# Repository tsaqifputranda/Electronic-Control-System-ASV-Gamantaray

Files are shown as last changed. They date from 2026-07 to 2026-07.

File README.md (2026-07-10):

# 🔧 Electronic (Control System) - ASV Gamantaray

Selamat datang di dokumentasi sistem kontrol elektronika kapal otonom Gamantaray.

## 📋 Daftar Isi Dokumentasi
1. **Project Overview** (Halaman Utama)
2. [Spesifikasi Sistem (Requirements)](./02_Requirements/requirements.md)
3. [Arsitektur & Diagram Blok](./03_System_Architecture/architecture.md)
4. [Desain Hardware & PCB](./04_Hardware_Design/hardware_desain.md)
5. [Power Management](./05_Power_Management/power_management.md)
6. [Wiring & Integration](./06_Wiring_&_Integration/integration_notes.md)
7. [Testing](./07_Testing/test_procedures.md)
8. [Problem & Solution](./08_Problem_&_Solution/troubleshooting.md)
9. [Final Evaluation](./09_Final_Evaluation/final_evaluation.md)
10. [Next Generation Notes](./10_Next_Generation_Notes/next_generation_notes.md)

---

## 🔌 Diagram Blok Sistem Utama
Untuk gambaran cepat mengenai interkoneksi sistem, kamu bisa melihat ringkasan diagram melalui tautan di bawah ini:

* ⚡ [Buka Diagram Blok Distribusi Daya Sistem Kontrol](./03_System_Architecture/PDB_Control_System_Diagram.jpg)
* 🗺️ [Buka Diagram Arsitektur Komunikasi Antar Komponen](./03_System_Architecture/Communication_Architecture_Diagram.jpg)

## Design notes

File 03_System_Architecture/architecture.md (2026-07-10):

# 🏗️ Arsitektur Sistem, Komunikasi & Pengabelan ASV Gamantaray 

Dokumen ini menjelaskan arsitektur tingkat tinggi (high-level architecture), topologi jaringan komunikasi, serta detail pengabelan sinyal kontrol pada kapal otonom ASV Gamantaray Safinah One 2026.

---

## 1. Arsitektur Jaringan & Distribusi Komponen (System Architecture)

Diagram di bawah ini menunjukkan distribusi fisik komponen antara lambung kapal (Hull A & Hull B), susunan geladak (Deck A & Deck B), serta jalur komunikasi ke Stasiun Pengendali Darat (Ground Control Station - GCS).

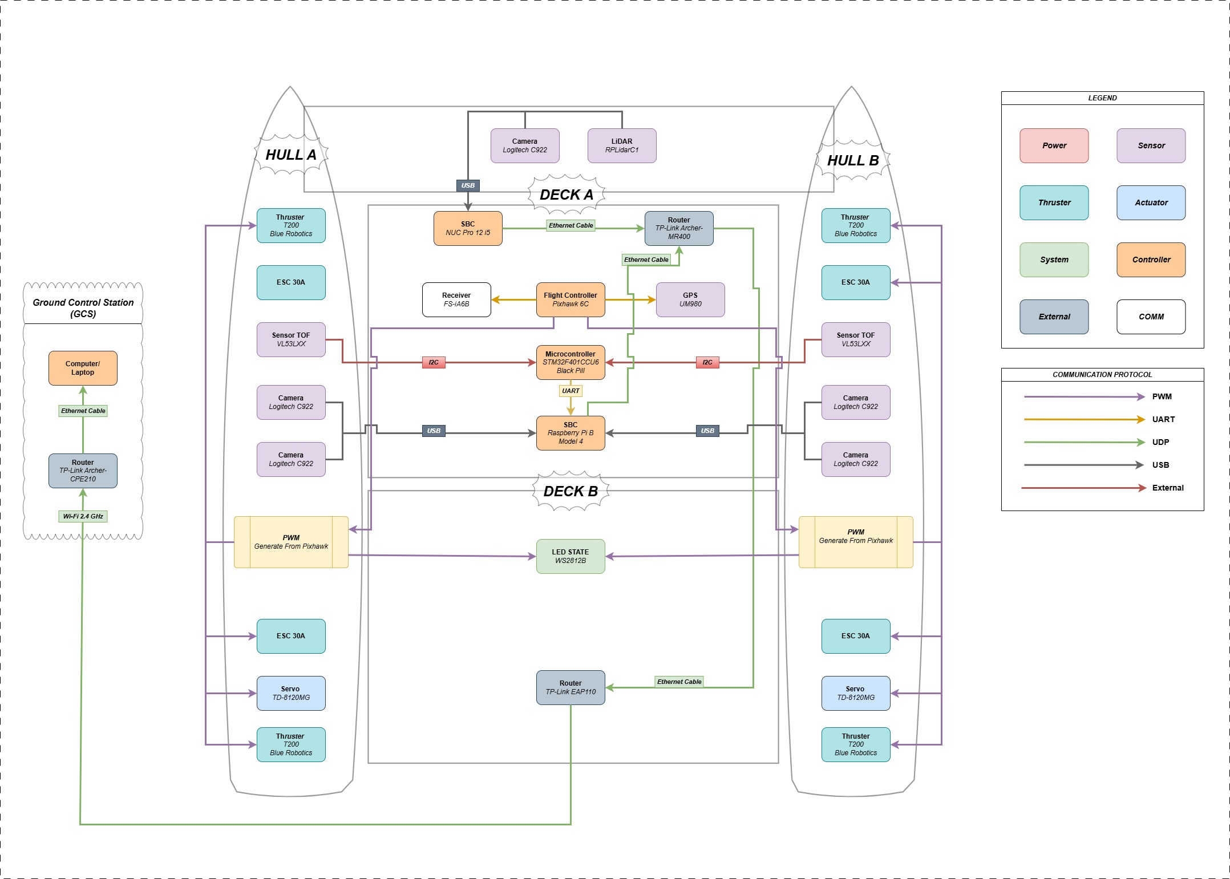
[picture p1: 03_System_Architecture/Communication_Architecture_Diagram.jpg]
Arsitektur Komunikasi Sistem


### A. Pembagian Kompartemen Fisik
* **HULL A & HULL B (Sistem Penggerak & Sensor Samping):** Masing-masing lambung dilengkapi dengan 2x Thruster Blue Robotics T200 (dikendalikan via ESC 30A), 1x Servo TD-8120MG untuk artikulasi mekanik, 1x Sensor Jarak TOF VL53LXX, dan 2x Kamera Logitech C922.
* **DECK A (Pusat Komputasi & Navigasi):** Berisi komponen komputasi utama (Intel NUC & Raspberry Pi 4), Flight Controller Pixhawk 6C, Mikrokontroler STM32 Black Pill, Modul GPS UM980, dan Router Utama TP-Link Archer-MR400.
* **DECK B (Sistem Jaringan Luar & Indikator):** Pada bangunan atas kapal diletakkan router TP-Link EAP110 untuk transmisi nirkabel jarak jauh dan modul LED State WS2812B.

### B. Protokol Komunikasi Data
Sistem ini memanfaatkan 5 jenis protokol komunikasi utama untuk menjamin koordinasi antar-perangkat:

| Protokol | Jalur Koneksi (Dari $\rightarrow$ Ke) | Fungsi / Data yang Ditransmisikan |
| :---: | :--- | :--- |
| **UDP (Ethernet)** | Intel NUC, RPi 4, Pixhawk 6C, EAP110 $\rightarrow$ Router MR400 | Jaringan lokal (*LAN*) kapal & interkoneksi data ROS/MAVLink kecepatan tinggi |
| **Wi-Fi 2.4 GHz** | GCS (TP-Link CPE210) $\leftrightarrow$ Kapal (TP-Link EAP110) | Jalur telemetri, data sensor, dan kendali otonom jarak jauh dari darat |
| **UART / Serial** | • Pixhawk 6C $\leftrightarrow$ Raspberry Pi 4<br>• STM32 Black Pill $\rightarrow$ Raspberry Pi 4<br>• Pixhawk 6C $\rightarrow$ GPS UM980 | • Pengiriman data navigasi/status<br>• Pengiriman data sensor jarak (*Trigger*) |
| **I2C** | STM32 Black Pill $\leftrightarrow$ 2x Sensor TOF VL53LXX | Pembacaan data jarak digital dari lambung A dan B |
| **USB** | • Intel NUC $\leftrightarrow$ RPLidarC1 & 1x Kamera C922<br>• Raspberry Pi 4 $\leftrightarrow$ 4x Kamera C922 | Transfer data sensor spasial (LiDAR) & streaming video *Computer Vision* |
| **PWM** | Pixhawk 6C $\rightarrow$ ESC 30A & Servo TD-8120MG | Sinyal kontrol kecepatan thruster dan posisi servo |

---

## 2. Diagram Pengabelan Detail Sinyal (Communication Wiring Diagram)

Diagram berikut menjelaskan detail pinout, interkoneksi elektrikal sinyal data, serta komponen pasif penunjang stabilitas sinyal pada Trigger System PCB dan Computer Vision System.

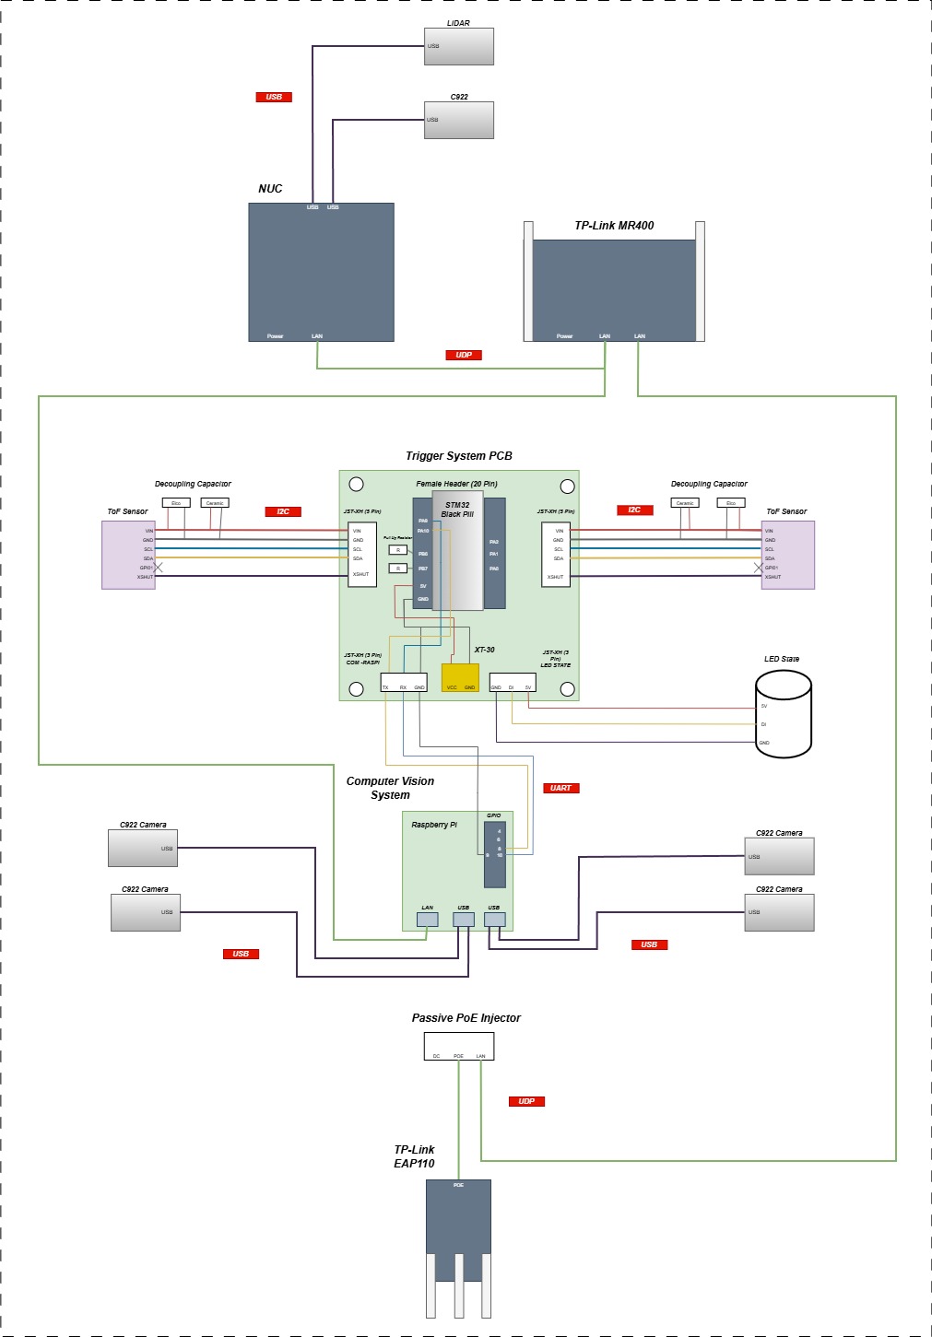
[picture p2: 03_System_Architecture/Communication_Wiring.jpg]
Diagram Pengabelan Komunikasi


### A. Sub-Sistem Trigger PCB (STM32F401 Black Pill)
* **Bus I2C & Penanganan Noise:** Sensor TOF terhubung ke pin I2C STM32 (`PB6` & `PB7`). Dilengkapi dengan **Resistor Pull-Up (R)** pada jalur data/jam serta kombinasi **Decoupling Capacitor** (Kapasitor Elektrolit + Keramik) secara paralel di dekat sensor untuk memfilter noise tegangan. Pin `PA0` dan `PA1` digunakan sebagai jalur `XSHUT` untuk mengaktifkan/mematikan sensor secara sekuensial guna menghindari tabrakan alamat (*address conflict*).
* **Interkoneksi ke Raspberry Pi:** Menggunakan konektor JST-XH 3-Pin via jalur **UART** (`PA9-TX` dan `PA10-RX`) untuk mengirimkan data jarak yang telah diolah.
* **Kontrol Lampu Indikator:** Pin `PA2 (LED STATE)` terhubung langsung ke pin *Data Input* (DI) pada modul **LED State WS2812B** melalui konektor JST-XH 3-Pin.

### B. Sub-Sistem Jaringan & Vision (Intel NUC & Raspberry Pi)
* **Manajemen Kamera:** Untuk mencegah *bottleneck* daya dan data, 4 unit kamera Logitech C922 ditangani oleh port USB Raspberry Pi 4, sedangkan 1 unit kamera utama bersama dengan **RPLidarC1** dihubungkan ke port USB Intel NUC Pro 12.
* **Topologi Jaringan Lokal:** Intel NUC dan Raspberry Pi terhubung ke port LAN **TP-Link MR400** menggunakan kabel Ethernet (UDP). Akses point outdoor **TP-Link EAP110** dihubungkan ke sistem jaringan melalui **Passive PoE Injector** untuk mendapatkan suplai daya sekaligus interkoneksi data ke router utama.

---

## 3. Arsitektur Manajemen Daya (Power Distribution Diagram)

Untuk mendukung kestabilan seluruh interkoneksi komunikasi di atas, daya didistribusikan dari baterai tunggal LiPo 14.8V melalui pembagian beberapa regulator khusus (*Multi-voltage Rail*).

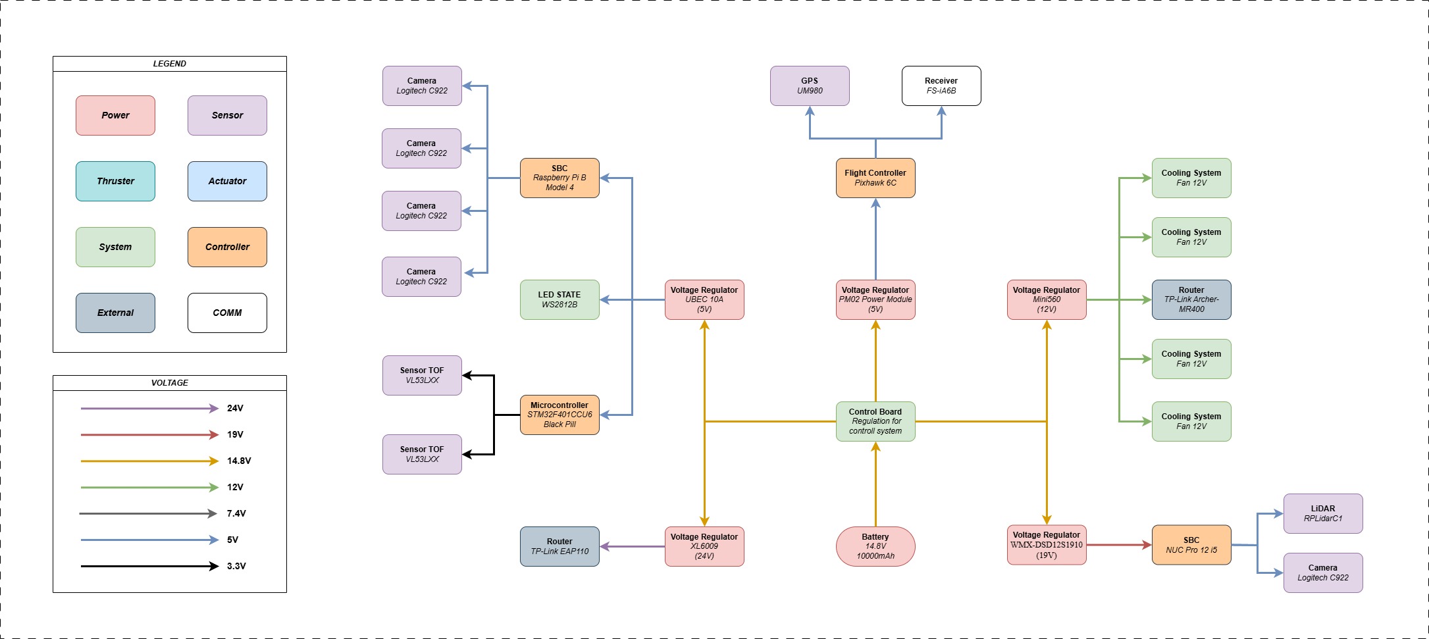
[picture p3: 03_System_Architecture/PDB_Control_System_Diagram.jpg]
Diagram Blok Distribusi Daya


* **Rail 5V (UBEC 10A):** Menjamin kestabilan daya untuk Raspberry Pi 4 yang mendrive 4 kamera sekaligus, STM32, serta LED State.
* **Rail 5V (PM02 Modul Daya):** Terisolasi khusus untuk Flight Controller Pixhawk 6C agar terhindar dari interferensi beban komputasi.
* **Rail 12V (Mini560):** Menyediakan daya untuk sistem pendingin (4x Fan 12V) dan Router TP-Link MR400.
* **Rail 19V (WMX Step-Up):** Menyuplai daya tinggi yang stabil untuk SBC Intel NUC Pro 12 i5.
* **Rail 24V (XL6009 Step-Up):** Khusus digunakan untuk menyuplai daya Router TP-Link EAP110.

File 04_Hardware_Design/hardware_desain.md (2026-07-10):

# 🛠️ Dokumentasi Desain Perangkat Keras (Hardware Design)

Dokumen ini memuat spesifikasi teknis, skematik, dan detail interkoneksi dari 2 unit PCB custom yang dirancang menggunakan **KiCad E.D.A.** untuk sistem kendali otonom ASV Gamantaray Safinah One 2026.

---

## 1. Board 1: Power Distribution Board (PDB) Control System
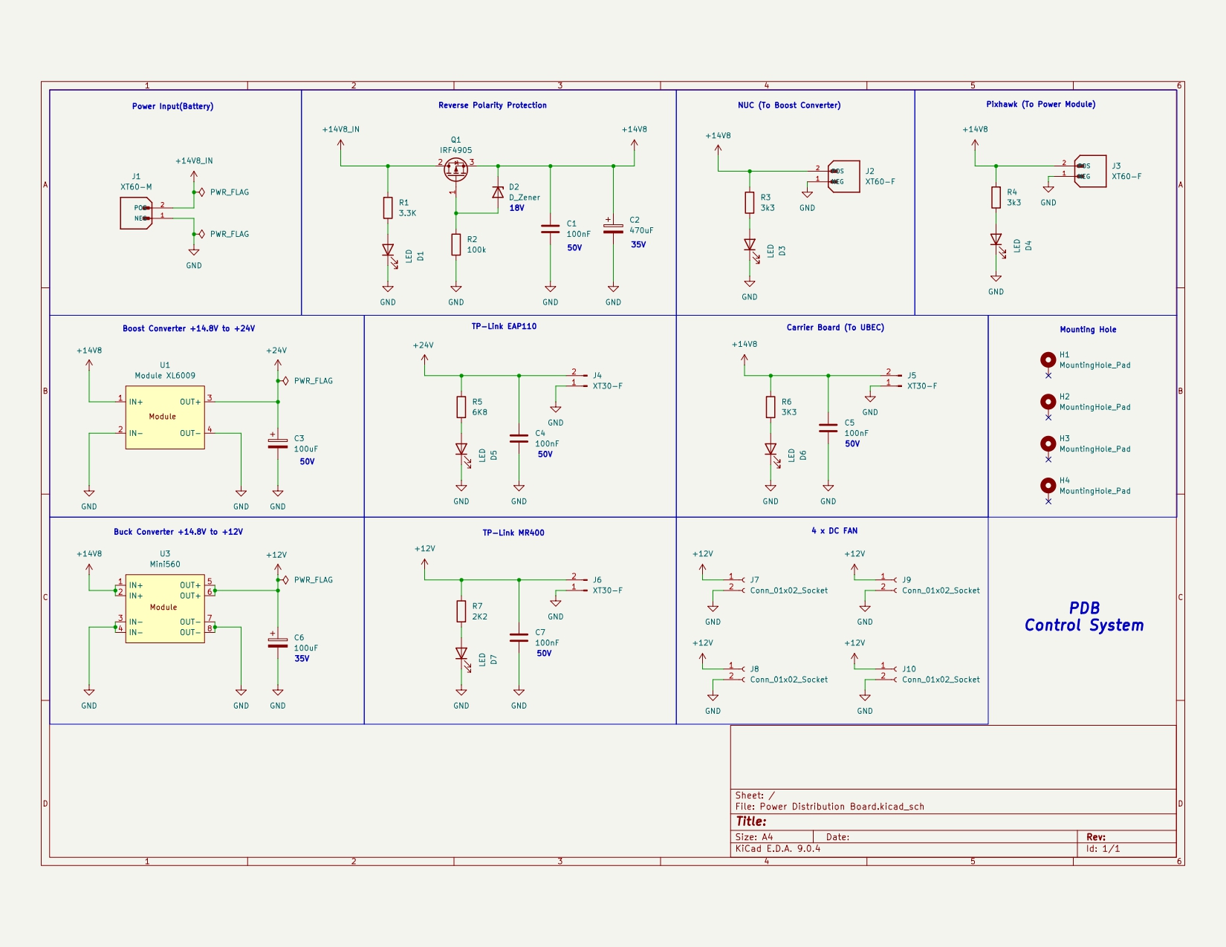
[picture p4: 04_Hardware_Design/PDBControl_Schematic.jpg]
PDB Control System Schematic
* **Skematik:** 
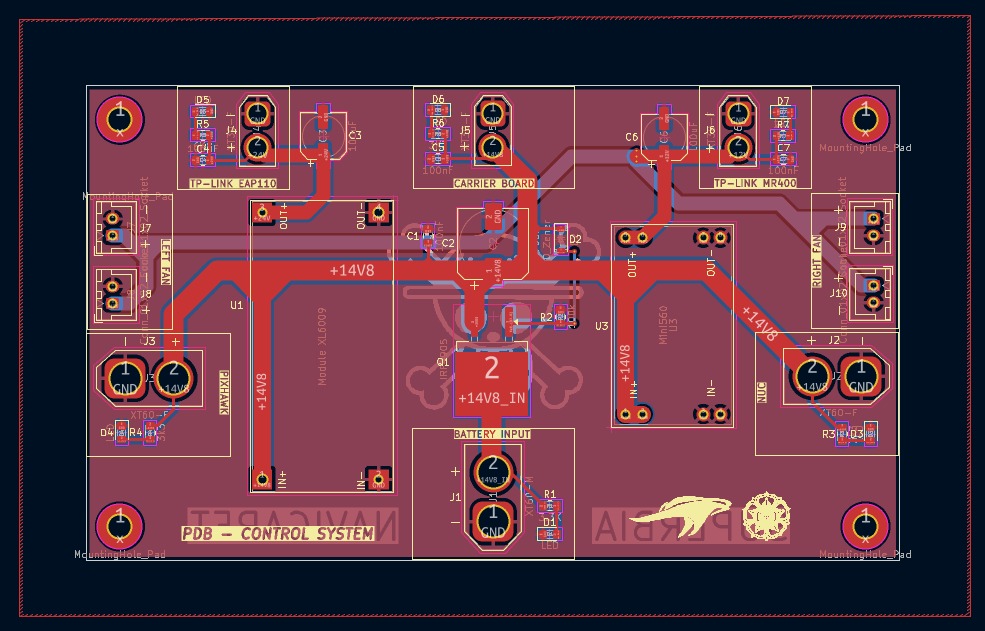
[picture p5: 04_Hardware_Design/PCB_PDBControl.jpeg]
PDB Control System PCB Layout
* **PCB Layout:** 
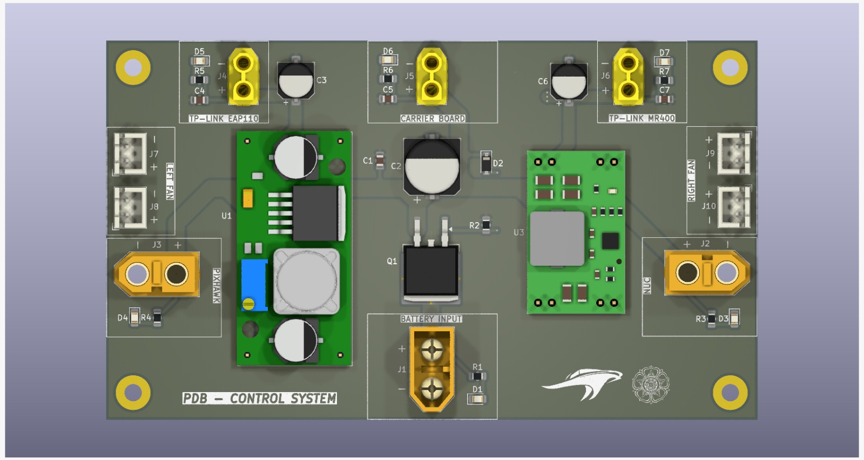
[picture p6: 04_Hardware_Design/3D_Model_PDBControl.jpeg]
PDB Control System 3D Model
* **3D Model:** 
* **Fungsi Utama:** Menerima daya dari baterai utama, menyediakan fitur proteksi, dan mendistribusikan tegangan (baik langsung maupun regulasi) ke seluruh sub-sistem kapal.

### A. Fitur Proteksi & Input Utama
* **Power Input (Battery):** Menggunakan konektor **XT60-M** menerima tegangan baterai LiPo 4S (+14.8V nominal, terlabel `+14VB`).
* **Reverse Polarity Protection (Proteksi Terbalik Kutub):** Menggunakan P-Channel MOSFET **IRF4905 (Q1)**, Zener Diode 18V (D2) untuk membatasi $V_{gs}$, dan resistor pembagi tegangan 100kΩ (R2). Fitur ini melindungi seluruh sistem jika baterai tidak sengaja terpasang terbalik.
* **Bulk Filtering:** Dilengkapi dengan kapasitor *decoupling* dan *bulk* C1 (100nF 50V) serta C2 (470uF 35V) untuk meredam lonjakan tegangan (*voltage spike*).

### B. Daftar Jalur Distribusi Daya (Power Rails)

| Jalur Output | Konektor | Modul Regulator / Komponen | Komponen Tujuan | Fitur Indikator / Filter |
| :---: | :---: | :--- | :--- | :--- |
| **+14.8V (Direct)** | XT60-F (J2) | Direct Battery | PC Intel NUC (Menuju Boost Converter internal) | LED D3 (Resistor 3.3kΩ) |
| **+14.8V (Direct)** | XT60-F (J3) | Direct Battery | Pixhawk 6C (Menuju PM02 Power Module) | LED D4 (Resistor 3.3kΩ) |
| **+14.8V (Direct)** | XT30-F (J5) | Direct Battery | **PCB Carrier Board** (Menuju UBEC 5V) | LED D6, Kapasitor C5 (100nF) |
| **+24V (Regulated)**| XT30-F (J4) | **XL6009 Boost Converter** (U1) | Router TP-Link EAP110 | LED D5 (Resistor 6.8kΩ), C3 (100µF 50V) |
| **+12V (Regulated)**| XT30-F (J6) | **Mini560 Buck Converter** (U3) | Router TP-Link Archer-MR400 | LED D7 (Resistor 2.2kΩ), C6 (100µF 35V) |
| **+12V (Regulated)**| 4x Conn 2-Pin (J7-J10) | Pararel dari output Mini560 | 4x Cooling DC Fan 12V | Jalur pararel langsung untuk kipas pendingin |

### C. Download File 
* **File Skematik:** 💾 **[Download Schematic - PDB Control System](./PDB_Control_System.kicad_sch)**
* **File PCB Layout:** `💾 **[Download PCB Layout - PDB Control System](./PDB_Control_System.kicad_pcb)**
* **File 3D Model:** 💾 **[Download 3D Model - PDB Control System](./PCB_Carrier.step)**

---

## 2. Board 2: PCB Carrier Board (Sensor & Microcontroller Interface)
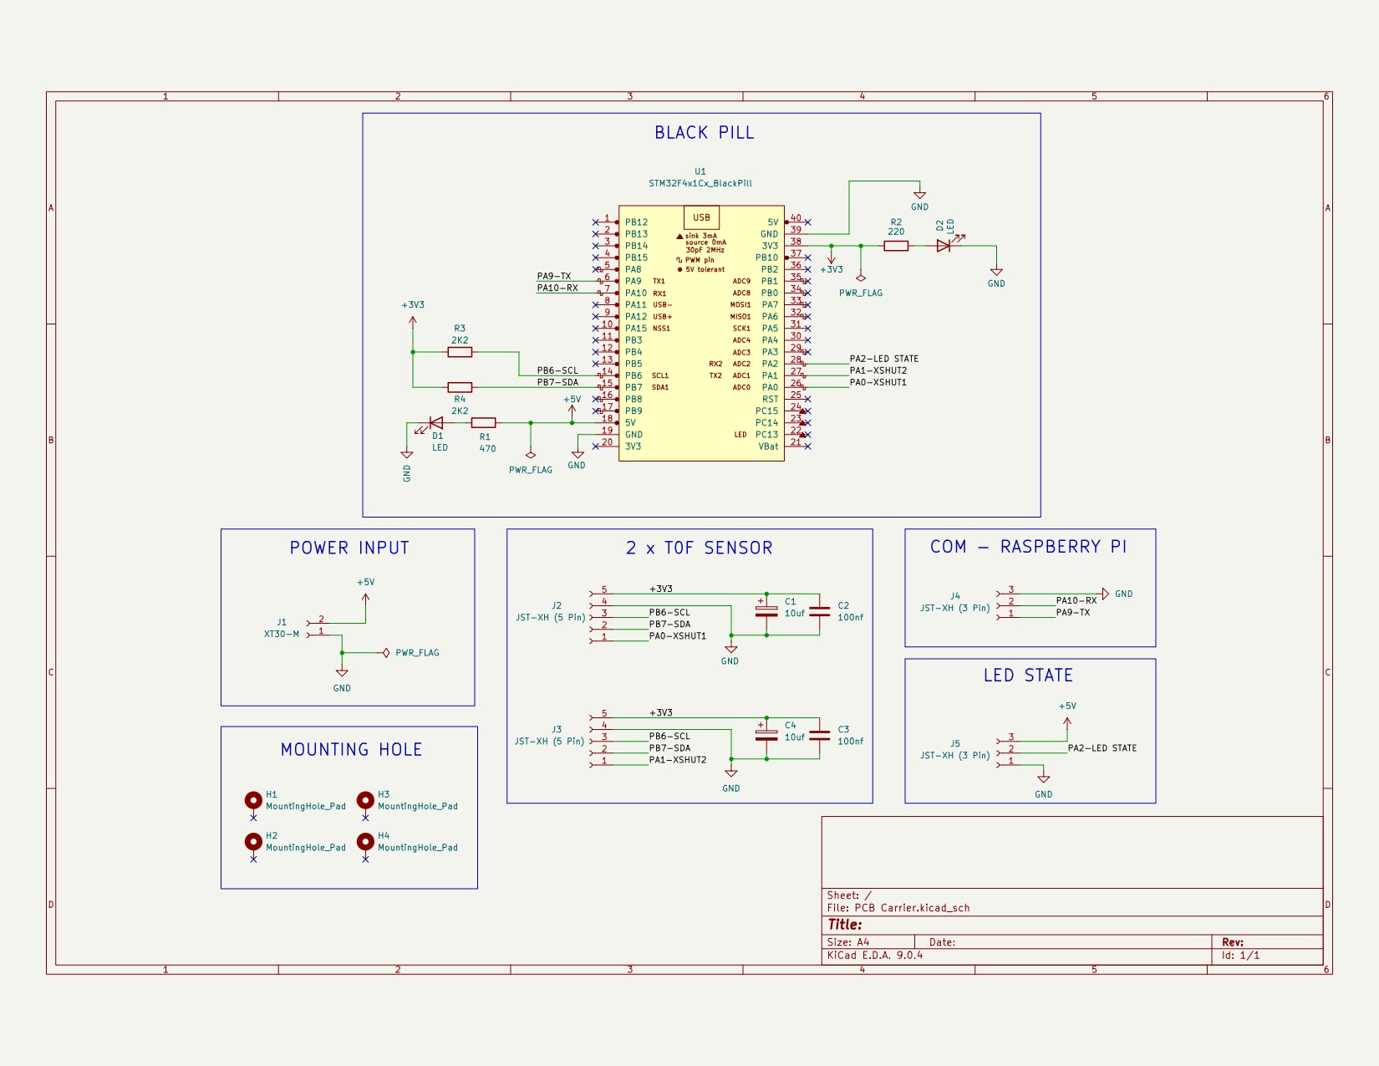
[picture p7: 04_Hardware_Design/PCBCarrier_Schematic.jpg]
Carrier Board Schematic
* **Skematik:** 
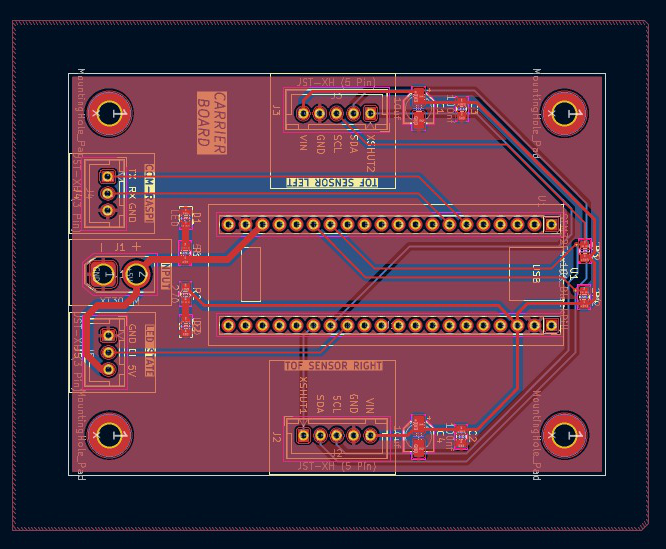
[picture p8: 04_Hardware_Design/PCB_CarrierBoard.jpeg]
Carrier Board PCB Layout
* **PCB Layout:** 
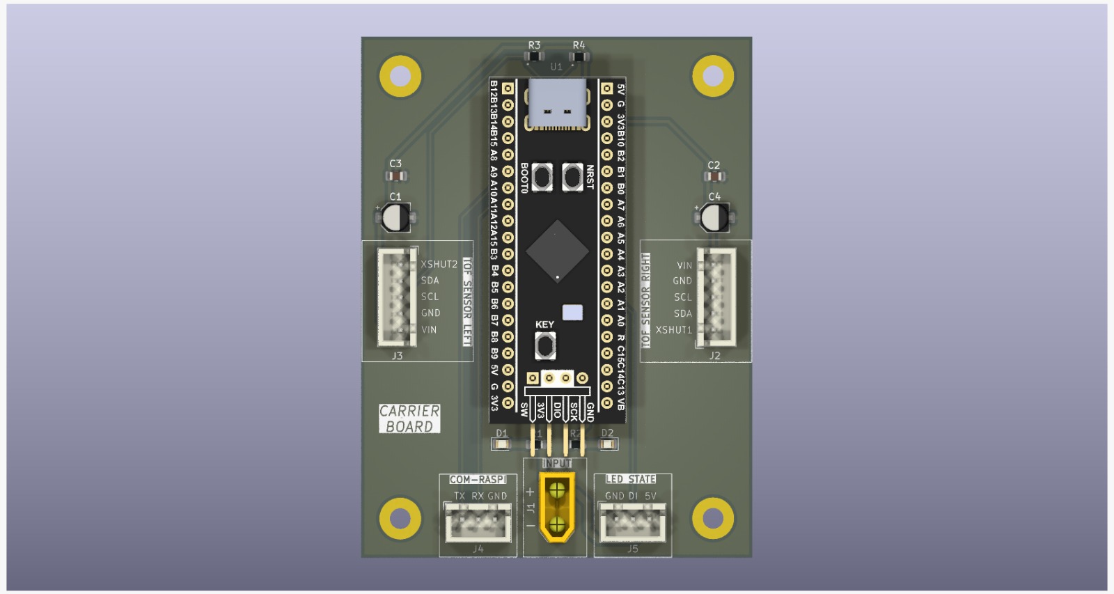
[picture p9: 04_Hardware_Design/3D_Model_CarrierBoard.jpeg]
Carrier Board 3D Model
* **3D Model:** 
* **Fungsi Utama:** Sebagai *breakout board* pusat untuk mikrokontroler STM32 Black Pill, manajemen sensor jarak (TOF), dan interkoneksi data ke Raspberry Pi serta aktuator indikator.

### A. Spesifikasi Power Input Board
* **Power Input:** Menggunakan konektor **XT30-M (J1)** yang menerima suplai tegangan **+5V DC** stabil yang diturunkan oleh UBEC dari PDB. 
* Terdapat LED Indikator Daya Utama (D1) dengan resistor pembatas arus 470Ω (R1).

### B. Konfigurasi Mikrokontroler & Perifer (STM32 Black Pill)
Board ini mengintegrasikan **STM32F4x1Cx Black Pill (U1)** dengan pemetaan pinout sebagai berikut:

#### 1. Jalur Komunikasi I2C (Dual TOF Sensor)
Menggunakan dua sensor Time-of-Flight (TOF) berbasis JST-XH 5-Pin. Jalur bus I2C (SCL & SDA) ditarik ke atas (*pulled-up*) menggunakan resistor **2.2kΩ (R3 & R4)** ke jalur `+3V3` untuk stabilitas data.
* **Konektor TOF 1 (J2):** 
  * Pinout: Pin 1 (`PA0-XSHUT1`), Pin 2 (`PB7-SDA`), Pin 3 (`PB6-SCL`), Pin 4 (`GND`), Pin 5 (`+3V3`).
  * Filter: Kapasitor C1 (10µF) & C2 (100nF).
* **Konektor TOF 2 (J3):** 
  * Pinout: Pin 1 (`PA1-XSHUT2`), Pin 2 (`PB7-SDA`), Pin 3 (`PB6-SCL`), Pin 4 (`GND`), Pin 5 (`+3V3`).
  * Filter: Kapasitor C4 (10µF) & C3 (100nF).

#### 2. Jalur Komunikasi Serial (COM - Raspberry Pi)
Komunikasi data *low-level* ke *high-level computer* dijembatani via konektor **JST-XH 3-Pin (J4)** menggunakan protokol UART/Serial:
* Pin 1: `PA9-TX` (Mengirim data dari STM32 ke RX Raspberry Pi)
* Pin 2: `PA10-RX` (Menerima data di STM32 dari TX Raspberry Pi)
* Pin 3: `GND` (Grounding bersama)

#### 3. Indikator LED State (WS2812B)
Output sinyal kontrol untuk lampu indikator status kapal dihubungkan via konektor **JST-XH 3-Pin (J5)**:
* Pin 1: `GND`
* Pin 2: `PA2-LED STATE` (Pin kontrol data addressable LED)
* Pin 3: `+5V` (Suplai daya LED strip)

### C. Download File 
* **File Skematik:** 💾 **[Download Schematic - Carrier Board](./Carrier_Board.kicad_sch)**
* **File PCB Layout:** `💾 **[Download PCB Layout - Carrier Board](./Carrier_Board.kicad_pro.kicad_pcb)**
* **File 3D Model:** 💾 **[Download 3D Model - Carrier Board](./PCB_Carrier.step)**

---

##  Fitur Mekanik
* Kedua PCB dilengkapi dengan **4x Mounting Hole Pad (H1 - H4)** berukuran standar untuk pemasangan baut spacer kokoh di dalam box komponen ASV.

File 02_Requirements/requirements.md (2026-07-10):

# 📋 Spesifikasi Sistem & Kebutuhan Elektronika ASV Gamantaray

Dokumen ini mencakup spesifikasi komponen, tegangan kerja, dan perangkat keras yang digunakan pada sistem kontrol elektronik ASV Gamantaray berdasarkan desain sistem SAFINAH ONE 2026.

### 1. Spesifikasi Sumber Daya Utama
* **Baterai Utama:** LiPo 4S (14.8V, 10000 mAh, 25C).
* **Sistem Distribusi Daya:** Menggunakan Control Board pusat (PDB - Contol System) untuk regulasi ke 5 voltage rails utama (5V, 12V, 19V, 24V, dan internal 3.3V).

### 2. Daftar Komponen & Perangkat Keras Utama

| Kategori | Komponen / Device | Spesifikasi / Tipe | Peran Spesifik |
| :--- | :--- | :--- | :--- |
| **Controllers** | Flight Controller | Pixhawk 6C | Pengendali navigasi utama & otonom |
| | High-End SBC | Intel NUC Pro 12 i5 | Pemrosesan data berat (LiDAR & Visi) |
| | Low-End SBC | Raspberry Pi 4 Model B | Manajemen multi-kamera & indikator |
| | Microcontroller | STM32F4x1Cx (Black Pill) | Pemrosesan sensor jarak (TOF) |
| **Sensors** | LiDAR | RPLidarC1 | Pemetaan lingkungan sekitar & deteksi objek |
| | Vision / Camera | Logitech C922 (5 Units) | 4x pada RPi 4, 1x pada Intel NUC |
| | Distance Sensor | Sensor TOF VL53LXX (2 Units) | Sensor pendeteksi jarak dekat |
| | GNSS / GPS | UM980 | Modul navigasi satelit akurasi tinggi |
| **COMM / Network**| Remote Receiver | FS-iA6B | Komunikasi manual RC (Radio Control) |
| | Router 1 | TP-Link Archer-MR400 | Jaringan lokal & internet kapal (12V) |
| | Router 2 | TP-Link EAP110 | Jaringan akses poin eksternal (24V) |
| **System Support**| Cooling System | Fan 12V (4 Units) | Sirkulasi udara & pendingin box elektronik |
| | Indicator | LED State WS2812B | Lampu indikator status kapal |

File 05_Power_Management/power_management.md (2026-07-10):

# ⚡ Power Budget Analysis & Control System Endurance Estimation

Dokumen ini memuat analisis konsumsi daya teoritis murni untuk **Sistem Kontrol, Komputasi, dan Komunikasi** ASV Gamantaray. Sistem propulsi (Thruster & ESC) menggunakan baterai dan jalur distribusi daya terpisah untuk menghindari kendala interferensi elektrikal (*electrical noise*).

### 🔋 Spesifikasi Sumber Daya Sistem Kontrol
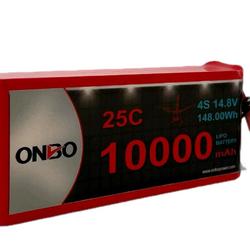
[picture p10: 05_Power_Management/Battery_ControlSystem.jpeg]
Battery For Control System

* **Tipe Baterai:** LiPo 4S (4 Sel) khusus sistem kontrol
* **Tegangan Nominal:** 14.8 V
* **Kapasitas:** 10000 mAh (10 Ah)
* **Discharge:** 25C
* **Safety Limit (Aturan 80%):** Maksimal kapasitas yang digunakan adalah 8000 mAh (8 Ah) demi menjaga kesehatan sel baterai.

---

## 1. Tabel Konsumsi Daya Elektronika (Control System Power Budget)

Arus pada komponen di bawah ini dihitung berdasarkan tegangan kerja masing-masing setelah melewati regulator (5V, 12V, 19V, 24V) yang bersumber dari Control Board utama.

| Komponen / Sub-Sistem | Tegangan Kerja (V) | Arus Nominal (A) | Arus Peak (A) | Daya Nominal (W) | Daya Peak (W) |
| :--- | :---: | :---: | :---: | :---: | :---: |
| **SBC Intel NUC Pro 12 i5** | 19.0 V | 1.50 A | 3.00 A | 28.50 W | 57.00 W |
| **SBC Raspberry Pi 4 B + 4x Cam** | 5.0 V | 2.50 A | 5.00 A | 12.50 W | 25.00 W |
| **Pixhawk 6C + Perifer + 2x Servo** | 5.0 V | 0.80 A | 3.00 A | 4.00 W | 15.00 W |
| **Router TP-Link Archer-MR400 + 4x Fan**| 12.0 V | 0.80 A | 1.50 A | 9.60 W | 18.00 W |
| **Router TP-Link EAP110** | 24.0 V | 0.20 A | 0.50 A | 4.80 W | 12.00 W |
| **STM32 Black Pill + 2x TOF Sensor** | 5.0 V | 0.10 A | 0.20 A | 0.50 W | 1.00 W |
| **TOTAL KEBUTUHAN DAYA ELEKTRONIKA** | - | - | - | **59.90 W** | **128.00 W** |

---

## 2. Perhitungan Energi Tersedia (Usable Energy)

1. Total Energi Teoretis Baterai:
   E_total = Kapasitas (Ah) x Tegangan Nominal (V)
   E_total = 10 Ah x 14.8 V = 148 Wh

2. Energi yang Aman Digunakan (80% Usable Capacity):
   E_usable = 148 Wh x 0.80 = 118.4 Wh

3. Efisiensi Regulator Daya (Losses Factor):
   Regulator DC-to-DC (Mini560, XL6009, WMX) pada PDB memiliki efisiensi rata-rata ~88%. Oleh karena itu, daya beban aktual yang ditarik dari baterai akan sedikit lebih tinggi dari daya nominal komponen resmi.

---

## 3. Estimasi Daya Tahan Baterai Sistem Kontrol (Endurance Estimation)

Perhitungan daya tahan baterai kontrol dibagi menjadi dua skenario beban kerja komputasi:

### Skenario A: Nominal / Cruise Operational Mode
Skenario normal saat kapal berlayar otonom melakukan misi. Seluruh komputer, router, dan sensor aktif memproses data secara konstan.
* Total Daya Komponen: 59.90 W
* Daya Aktual dari Baterai (Telah memperhitungkan efisiensi regulator 88%): 59.90 W / 0.88 = 68.07 W
* Rumus: Endurance = E_usable / Daya Aktual Nominal
* Perhitungan: 118.4 Wh / 68.07 W = 1.74 Jam
* **Estimasi Endurance Sistem Kontrol: ± 1 Jam 44 Menit**

### Skenario B: Peak Operational Mode (Beban Komputasi Maksimum)
Skenario ekstrim saat Intel NUC sedang melakukan pemrosesan algoritma pemetaan/AI yang berat, semua kamera melakukan *streaming* penuh, dan servo bergerak konstan secara simultan.
* Total Daya Peak Komponen: 128.00 W
* Daya Aktual dari Baterai (Telah memperhitungkan efisiensi regulator 88%): 128.00 W / 0.88 = 145.45 W
* Rumus: Endurance = E_usable / Daya Aktual Peak
* Perhitungan: 118.4 Wh / 145.45 W = 0.81 Jam
* **Estimasi Endurance Terendah: ± 49 Menit**

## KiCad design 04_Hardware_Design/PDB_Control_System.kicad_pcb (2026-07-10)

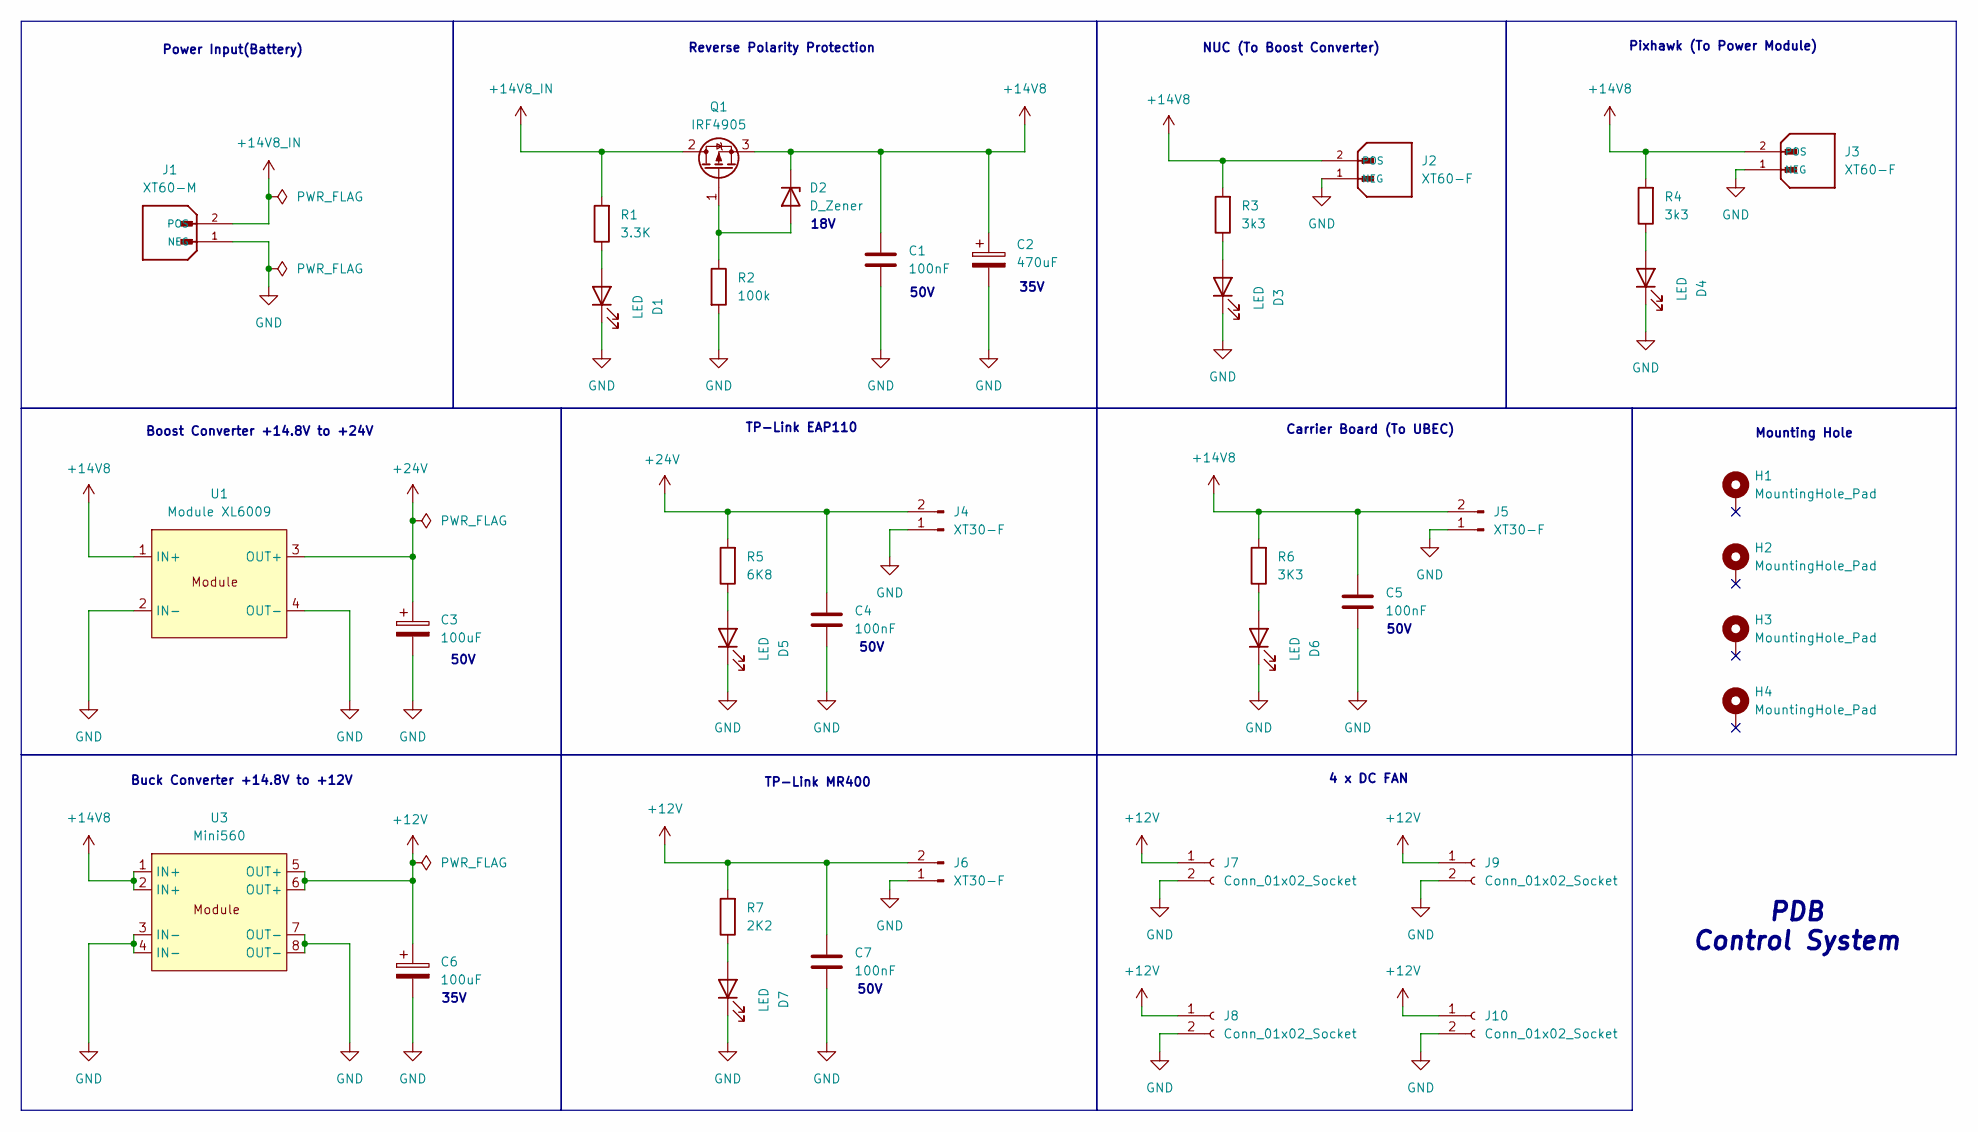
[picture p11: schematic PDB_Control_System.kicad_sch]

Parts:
C1, C4, C5, C7: 100nF; C_0805_2012Metric_Pad1.18x1.45mm_HandSolder
C2: 470uF; CP_Elec_10x10
C3, C6: 100uF; CP_Elec_6.3x5.4
D1, D3, D4, D5, D6, D7: LED; LED_0805_2012Metric_Pad1.15x1.40mm_HandSolder
D2: D_Zener; D_SOD-123
H1, H2, H3, H4: MountingHole_Pad; MountingHole_3.2mm_M3_Pad
J1: XT60-M; AMASS_XT60-M_1x02_P7.20mm_Vertical; PARTREV V1.2
J2, J3: XT60-F; AMASS_XT60-F_1x02_P7.20mm_Vertical
J4, J5, J6: XT30-F; AMASS_XT30U-F_1x02_P5.0mm_Vertical_custom
J7, J8, J9, J10: Conn_01x02_Socket; JST_XH_B2B-XH-A_1x02_P2.50mm_Vertical
Q1: IRF4905; TO-263-2
R1: 3.3K; R_0805_2012Metric_Pad1.20x1.40mm_HandSolder
R2: 100k; R_0805_2012Metric_Pad1.20x1.40mm_HandSolder
R3, R4: 3k3; R_0805_2012Metric_Pad1.20x1.40mm_HandSolder
R5: 6K8; R_0805_2012Metric_Pad1.20x1.40mm_HandSolder
R6: 3K3; R_0805_2012Metric_Pad1.20x1.40mm_HandSolder
R7: 2K2; R_0805_2012Metric_Pad1.20x1.40mm_HandSolder
U1: Module XL6009; XL6009 Module
U3: Mini560; Module Mini560

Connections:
+12V: C6.1, C7.1, J6.2, J7.1, J8.1, J9.1, J10.1, R7.2, U3.5 (OUT+), U3.6 (OUT+)
+14V8: C1.1, C2.1, C5.1, D2.1 (K), J2.2 (POS), J3.2 (POS), J5.2, Q1.3 (S), R3.2, R4.2, R6.2, U1.1 (IN+), U3.1 (IN+), U3.2 (IN+)
+14V8_IN: J1.2 (POS), Q1.2 (D), R1.2
+24V: C3.1, C4.1, J4.2, R5.2, U1.3 (OUT+)
GND: C1.2, C2.2, C3.2, C4.2, C5.2, C6.2, C7.2, D1.1 (K), D3.1 (K), D4.1 (K), D5.1 (K), D6.1 (K), D7.1 (K), J1.1 (NEG), J2.1 (NEG), J3.1 (NEG), J4.1, J5.1, J6.1, J7.2, J8.2, J9.2, J10.2, R2.2, U1.2 (IN-), U1.4 (OUT-), U3.3 (IN-), U3.4 (IN-), U3.7 (OUT-), U3.8 (OUT-)
unnamed: D1.2 (A), R1.1
unnamed: D2.2 (A), Q1.1 (G), R2.1
unnamed: D3.2 (A), R3.1
unnamed: D4.2 (A), R4.1
unnamed: D5.2 (A), R5.1
unnamed: D6.2 (A), R6.1
unnamed: D7.2 (A), R7.1

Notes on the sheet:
50V
18V
NUC (To Boost Converter)
Buck Converter +14.8V to +12V
4 x DC FAN
Boost Converter +14.8V to +24V
TP-Link EAP110
35V
Mounting Hole
Pixhawk (To Power Module)
Reverse Polarity Protection
PDB Control System
Power Input(Battery)
Carrier Board (To UBEC)
TP-Link MR400

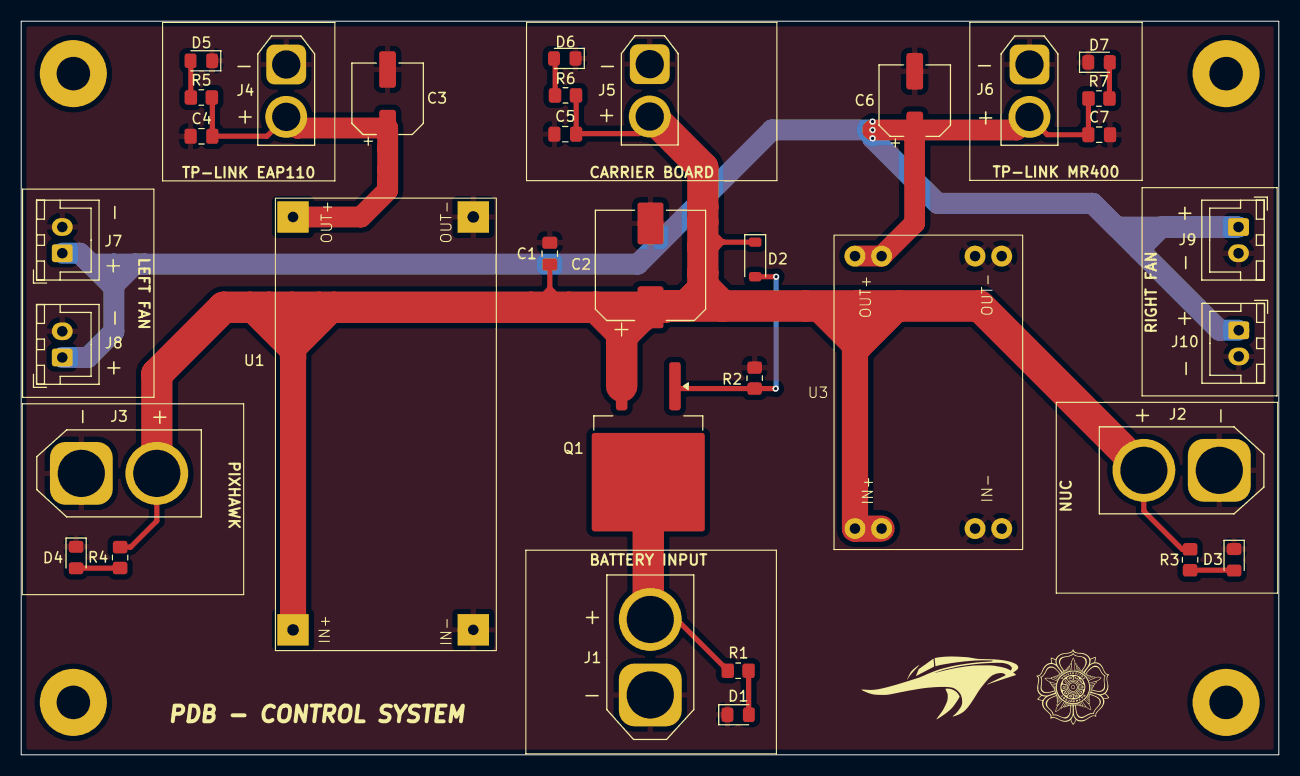
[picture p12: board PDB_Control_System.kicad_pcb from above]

Board: 2 copper layers, 120.0 x 70.0 mm, 38 parts (0 on the bottom side), 12 nets.

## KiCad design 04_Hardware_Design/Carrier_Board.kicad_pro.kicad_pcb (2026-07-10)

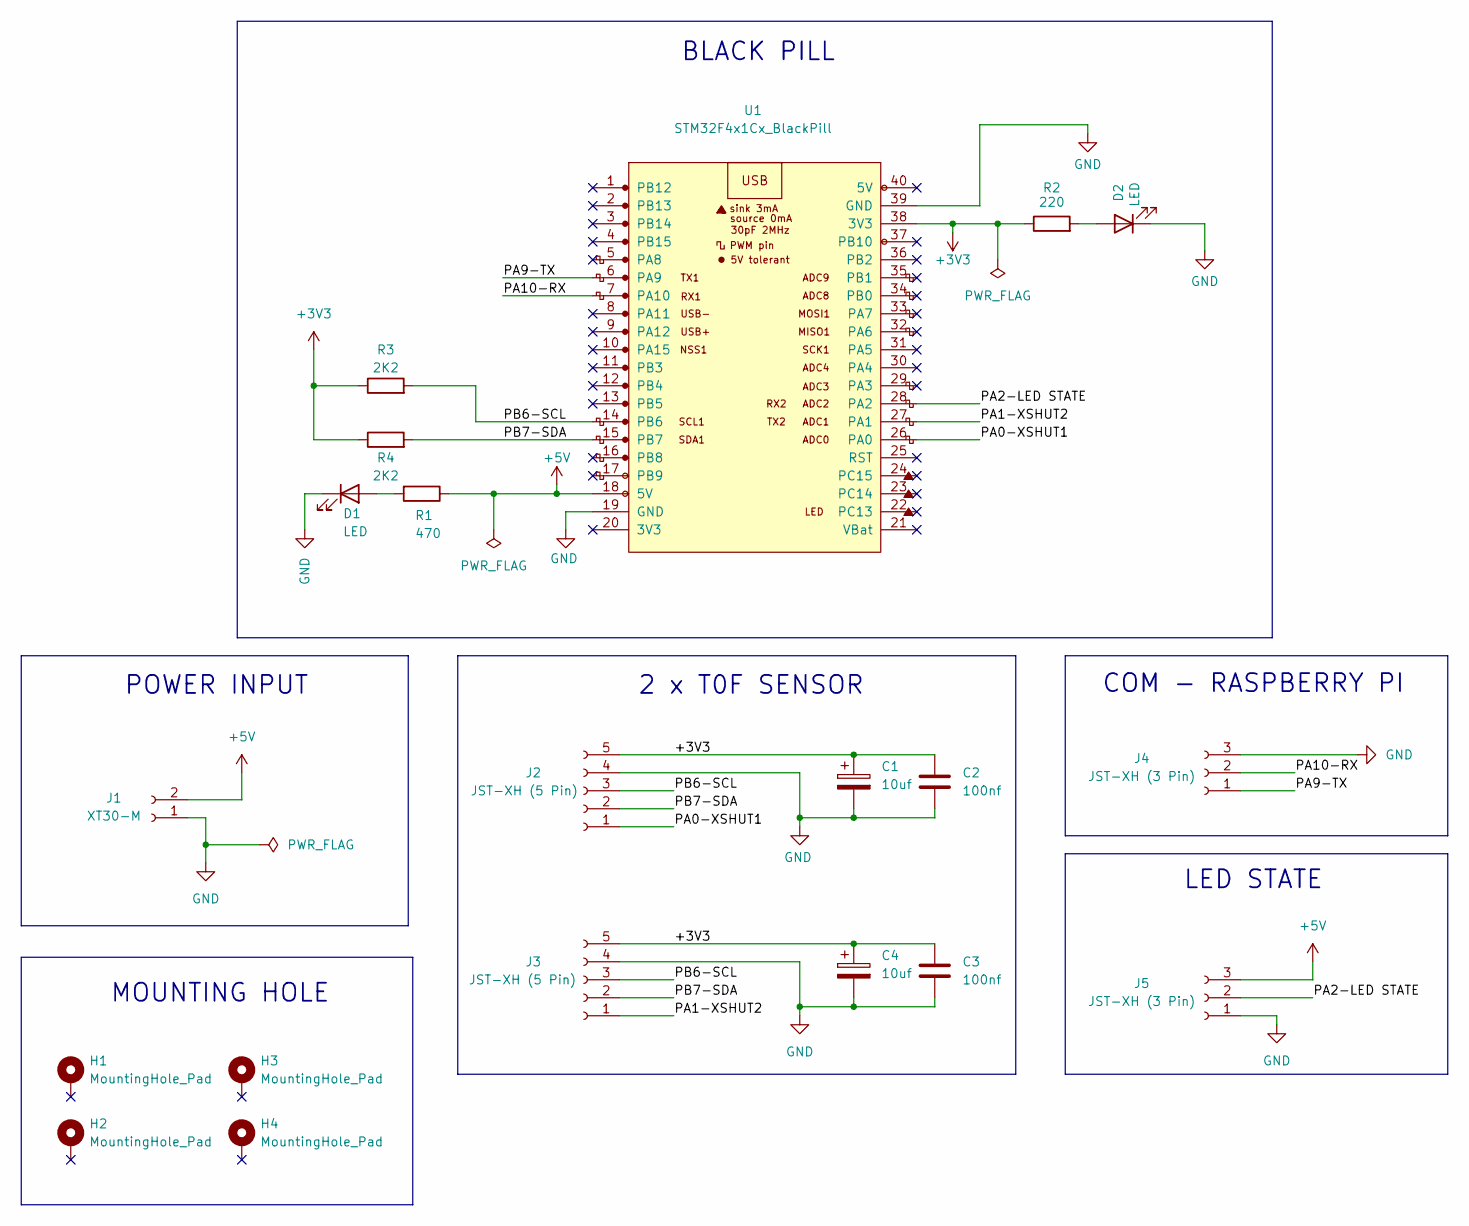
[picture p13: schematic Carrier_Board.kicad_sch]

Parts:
C1, C4: 10uf; CP_Elec_4x5.3
C2, C3: 100nf; C_0805_2012Metric_Pad1.18x1.45mm_HandSolder
D1, D2: LED; LED_0805_2012Metric
H1, H2, H3, H4: MountingHole_Pad; MountingHole_3.2mm_M3_Pad
J1: XT30-M; AMASS_XT30U-M_1x02_P5.0mm_Vertical
J2, J3: JST-XH (5 Pin); JST_XH_B5B-XH-A_1x05_P2.50mm_Vertical
J4, J5: JST-XH (3 Pin); JST_XH_B3B-XH-A_1x03_P2.50mm_Vertical
R1: 470; R_0805_2012Metric_Pad1.20x1.40mm_HandSolder
R2: 220; R_0805_2012Metric_Pad1.20x1.40mm_HandSolder
R3, R4: 2K2; R_0805_2012Metric_Pad1.20x1.40mm_HandSolder
U1: STM32F4x1Cx_BlackPill; STM32F4x1Cx_BlackPill_PartLike

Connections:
+3V3: C1.1, C2.1, C3.1, C4.1, J2.5, J3.5, R2.1, R3.1, R4.1, U1.38 (3V3)
+5V: J1.2, J5.3, R1.1, U1.18 (5V)
/PA0-XSHUT1: J2.1, U1.26 (PA0)
/PA1-XSHUT2: J3.1, U1.27 (PA1)
/PA2-LED STATE: J5.2, U1.28 (PA2)
/PA9-TX: J4.1, U1.6 (PA9)
/PA10-RX: J4.2, U1.7 (PA10)
/PB6-SCL: J2.3, J3.3, R3.2, U1.14 (PB6)
/PB7-SDA: J2.2, J3.2, R4.2, U1.15 (PB7)
GND: C1.2, C2.2, C3.2, C4.2, D1.1 (K), D2.1 (K), J1.1, J2.4, J3.4, J4.3, J5.1, U1.19 (GND), U1.39 (GND)
unnamed: D1.2 (A), R1.2
unnamed: D2.2 (A), R2.2

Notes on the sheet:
COM - RASPBERRY PI
POWER INPUT
MOUNTING HOLE
LED STATE
2 x T0F SENSOR
BLACK PILL

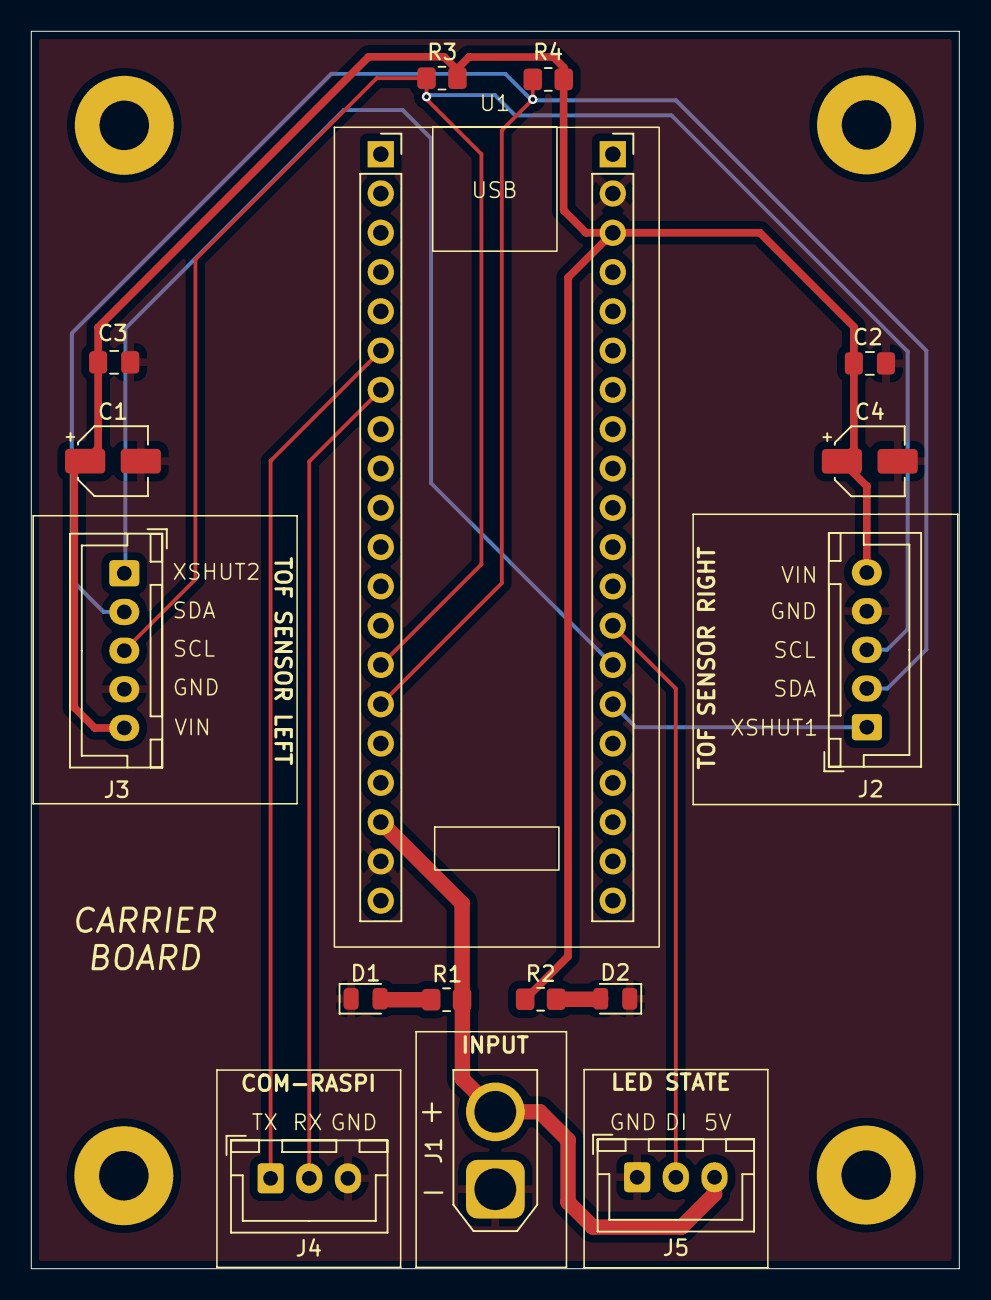
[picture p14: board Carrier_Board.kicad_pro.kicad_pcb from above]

Board: 2 copper layers, 60.0 x 80.0 mm, 20 parts (0 on the bottom side), 12 nets.

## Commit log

2026-07-10 Add system specifications for ASV control electronics
    Document system specifications for ASV control electronics, including voltage, power requirements, and main component needs.
2026-07-10 Rename Power Control Architecture Diagram (1).png to PDB Control System Diagram/architecture.md
2026-07-10 Add block diagram for Power Control System
2026-07-10 Enhance PDB Control System documentation
    Updated the hardware design documentation with schematic, PCB layout, and 3D model images along with download links.
